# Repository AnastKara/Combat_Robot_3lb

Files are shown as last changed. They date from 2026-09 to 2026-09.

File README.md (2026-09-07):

<!--
  RONIN — 3 lb Combat Robot README
  Placeholders marked [LIKE THIS] are details only you know; fill them in or
  reply and I'll update them.
-->

<div align="center">

# RONIN v1

### 3 lb (1.36 kg) Beetleweight Combat Robot — Horizontal Spinner








</div>

---

##  Quick Navigation

[Overview](#overview) · [Key Features](#key-features) · [Specifications](#technical-specifications) ([Chassis](#chassis) · [Drive](#drive-system) · [Power](#power-system) · [Electronics](#electronics)) · [Weapon](#weapon-system) · [Design & Engineering](#design--engineering) · [Assembly](#assembly-guide) · [Testing](#testing--calibration) · [Maintenance](#maintenance) · [BOM](#bill-of-materials-bom) · [Battle Record](#battle-record) · [Competition Notes](#competition-notes) · [Roadmap](#roadmap) · [Build Files](#build-files) · [Safety](#safety--rules-compliance) · [Credits](#credits) · [License](#license)

---

##  Overview

<div align="center">

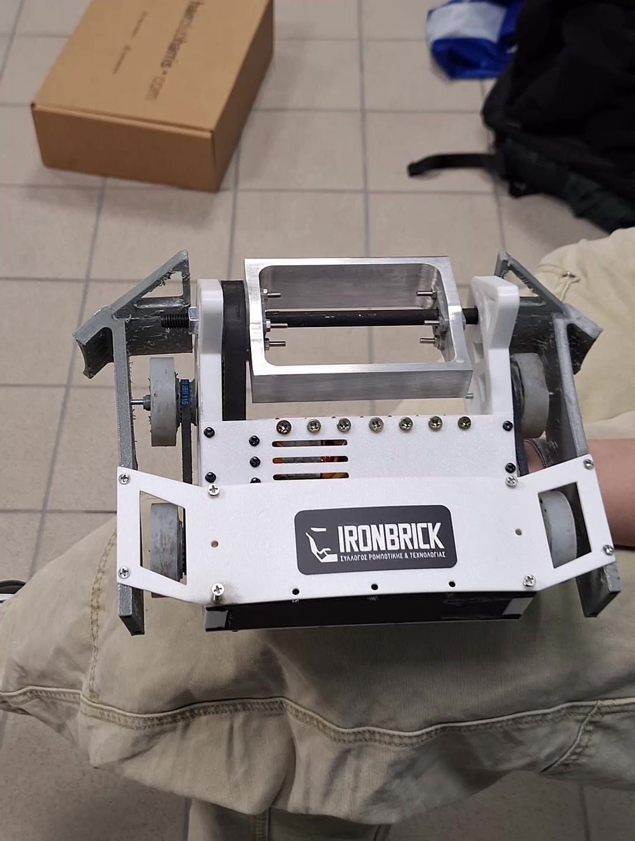
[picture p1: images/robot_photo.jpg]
RONIN v1 — 3 lb horizontal spinner robot
 &nbsp;
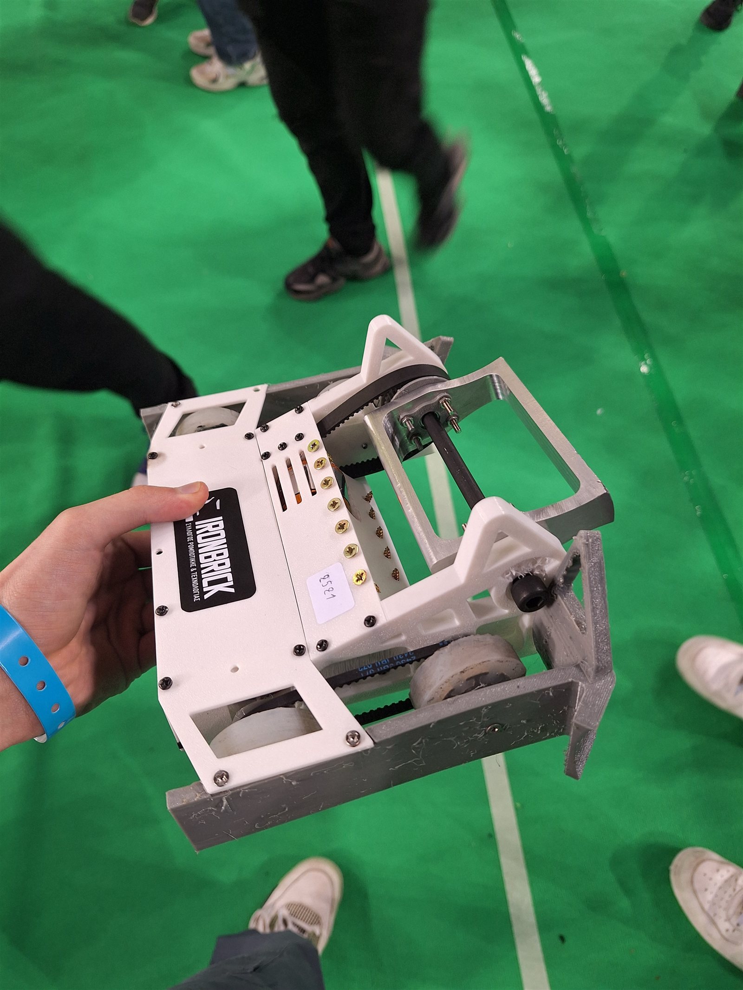
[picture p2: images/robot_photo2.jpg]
RONIN v1 — 3 lb horizontal spinner robot, second view


</div>

> _A compact, belt-driven 3 lb combat robot engineered for durability, ease of
> maintenance, and consistent performance in high-impact matches. RONIN pairs a
> high-energy horizontal spinner with a reinforced front wedge: robust drive
> power, efficient energy distribution, and a pointed front end built for
> pushing, deflecting, and controlling opponents._

Built for the **3 lb (1.36 kg) beetleweight class**, RONIN v1 is designed to be
**serviceable between matches** — a modular two-piece frame with clean wiring
and a lightweight multi-material build (printed PETG / TPU 95A frame with a
7075-T6 aluminum spinner bar) that keeps repair times short and combat
performance consistent. This document covers **RONIN v1**, the first
competition iteration; planned improvements are tracked in the
upgrade roadmap below.

 **Debut result: 2nd place at [MRC 2026](https://minoanrobotsports.gr/)** —
two knockout wins en route to the podium in the 3 lb knockout bracket.

---

##  Key Features

- **Horizontal spinner weapon** — 7075-T6 bar, brushless motor + 80 A ESC
- **Reinforced front wedge** — aggressive pushing, deflection, and positional control
- **Belt-driven dual-wheel drivetrain** — smooth, high-traction torque delivery
- **Modular 2-piece chassis** — fast repairs between matches
- **Shock-resistant electronics mounting** — foam-damped ESCs and secure routing
- **Clean internal wiring** — reliable and quick to troubleshoot
- **Competition-ready layout** — compatible with most 3 lb rule sets

---

##  Technical Specifications

###  Chassis
| Item | Specification |
| --- | --- |
| Material | PETG + TPU 95A (3D printed) |
| Manufacturing| Bambu Lab A1 Mini (FDM) |
| Architecture | 2-piece modular frame |
| Fasteners | M3 / M4 stainless steel |
| Dimensions | 220 × 160 × 91 mm (8.7 × 6.3 × 3.6 in) |
| Weight | **1150 g (2.54 lb)** _(3.0 lb / 1.36 kg max)_ |

###  Drive System
| Item | Specification |
| --- | --- |
| Drive type  | Belt-driven dual-wheel |
| Motor | 2× DartBox V2 Drive gearmotors (VIPER model) |
| Drive ESC | **WEKA 20A** Dual Brushed Motor Controller |
| Mainboard | **Just 'Cuz Motherboard V4** (Just 'Cuz Robotics) |
| Receiver | **FS2A** — AFHDS-2A protocol |
| Wheels | 43 mm (1.7 in) rubber / foam ([Silicon_Wheels](https://github.com/AnastKara/Silicon_Wheels)) |
| Belts | **S3M timing belts** (74 teeth · 4 mm)  |
| Top speed | **~3.5 m/s (12.6 km/h · 7.8 mph)** theoretical · ~2.6 m/s (9.4 km/h) realistic |

###  Power System
| Item | Specification |
| --- | --- |
| Battery | Tattu 3S LiPo · 11.1 V · 450 mAh · 75C |
| Connectors | XT30 |
| Power distribution| DartPCB (Just 'Cuz) |
| Safety | External power switch + removable link |

###  Weapon System
| Item | Specification |
| --- | --- |
| Type | Horizontal spinner (bar) |
| Weapon bar  | **7075-T6 aluminum** |
| Motor | D3536 brushless · **1450 kV** (current)|
| ESC | **80 A** brushless (current) |
| Upgrade | D3536 · 1200 kV + 40 A ESC (planned) |

###  Electronics
| Item | Specification |
| --- | --- |
| Mainboard | **Just 'Cuz Motherboard V4** (Just 'Cuz Robotics) |
| Drive ESC | **WEKA 20A** Dual Brushed Motor Controller |
| Weapon ESC | **80 A** brushless |
| Receiver | **FS2A** — AFHDS-2A protocol |
| Voltage regulation | 5 V BEC for receiver |
| Telemetry | LED status indicator |
| Transmitter | **FlySky FS-i6** — AFHDS-2A |

---

##  Design & Engineering

### Design Philosophy
RONIN is a **horizontal spinner with a control-game edge**. The 7075-T6 bar
delivers high-energy impacts that batter wedges, wheel mounts, and armor,
while the reinforced front wedge lets RONIN push and control opponents when the
weapon is spooled down. That philosophy drives three decisions:

- **Energy + control** — a high-energy weapon bar backed by a strong,
  belt-driven drivetrain that can out-push and out-position most opponents
- **Serviceability** — everything that commonly breaks (belts, wheels, weapon
  bar, drive ESC) is reachable within minutes between fights
- **Efficient weight budget** — the weapon, chassis, and drive get the weight;
  the electronics bay stays tight and clean

### Drivetrain
Two **DartBox V2 Drive gearmotors (VIPER model, 22 mm)** turn both wheels through
**S3M timing belts**, powered by the **WEKA 20A Dual Brushed Motor
Controller** and managed by the **Just 'Cuz Motherboard V4** mainboard. The
DartBox V2 motors are lightweight and ultra-powerful for their size, giving
RONIN a strong power-to-weight ratio. Belt drive reduces shock loading on
the motors and drivetrain during impacts — a key reliability win over direct
chain-drive setups — while the WEKA dual ESC delivers smooth, high-traction
torque for pushing matches.

>  **Top-speed estimate:** Based on the DartBox V2 Drive output (1550 RPM @ 3S)
> and 43 mm wheels, RONIN reaches ~3.5 m/s (12.6 km/h · 7.8 mph) theoretical
> no-load top speed. Accounting for battery sag, friction, and belt losses, a
> realistic figure is ~2.6 m/s (9.4 km/h · 5.9 mph).

| Drivetrain | Electronics |
| --- | --- |
| 2× DartBox V2 Drive (VIPER) + S3M belts | WEKA 20A dual ESC · JCMB V4 · FS2A |

### Weapon
RONIN's primary weapon is a **horizontal spinner bar** machined from
**7075-T6 aluminum**, spinning around a horizontal axis and powered by a
**D3536 brushless motor (1450 kV)** with an **80 A ESC**. The bar delivers
high-energy impacts that batter wedges, wheel mounts, and unprotected chassis.

A reinforced **front wedge** — a low-sweep, angled blade — tucks under
opponents for pushing and positional control when the weapon is down. Wedge
geometry is optimized for **steel arena floors**, and is re-torqued at every
event to keep engagement angle consistent.

| Weapon config | Bar | Motor | ESC |
| --- | --- | --- | --- |
| **Current** | 7075-T6  | D3536 · 1450 kV | 80 A |
| **Planned** | 7075-T6  | D3536 · 1200 kV | 40 A |

>  **Upgrade path:** The planned **D3536 · 1200 kV / 40 A** combination
> lightens the weapon sub-assembly and improves efficiency — trading a little
> top-end weapon speed for a smaller, simpler drive package.

### Chassis & Manufacturing
RONIN's modular frame is **3D printed on a Bambu Lab A1 Mini** in **PETG** for
structural rigidity, with **TPU 95A** parts where flexibility and shock
absorption matter. This multi-material approach keeps the robot lightweight,
reduces part count, and makes it fast to reprint spare parts between events.

---

##  Assembly Guide

### 1. Chassis Preparation
1. Install the front wedge using **M4 bolts**.
2. Mount side panels and check alignment.
3. Add the top plate **last** for easy internal access.

### 2. Drivetrain Installation
1. Mount the drive motors securely; apply **thread-locker**.
2. Align pulleys and tension the S3M belts.
3. Install wheels and verify free rotation.

### 3. Electronics Setup
1. Mount ESCs with **foam tape** for shock absorption.
2. Route motor wires cleanly along chassis walls.
3. Keep the receiver away from high-current lines.
4. Connect: **battery → PD board → ESCs → motors**.

### 4. Final Checks
- [ ] Verify belt tension
- [ ] Confirm correct motor direction
- [ ] Test radio failsafe
- [ ] Inspect all fasteners

---

##  Testing & Calibration

1. **No-load spin-up** — confirm smooth motor ramp with wheels off the ground.
2. **Steering response** — check left/right trim center and full-lock turns.
3. **Wedge engagement** — test on a flat surface; wedge should lift, not bounce.
4. **Thermal soak** — 1–2 minute drive test to confirm ESC and motor
   temperatures stay within limits.

---

##  Maintenance

- **Inspect belts** after every match — replace at the first sign of fraying
- **Re-tighten all screws**, especially the wedge bolts
- **Check motor bearings** for debris and re-grease as needed
- **Replace wheels** when worn to maintain consistent traction
- **Battery care** — keep Tattu 3S LiPos balanced and store them safely (450 mAh nominal)

---

##  Bill of Materials (BOM)

> 📎 CAD files (STEP) for every machined and printed part are in [Build Files](#build-files).

| Component | Specification | Source / Link |
| --- | --- | --- |
| Drive motor | 2× DartBox V2 Drive · VIPER 22 mm | [🔗 DartBox Drive](https://justcuzrobotics.com/products/dartbox-squared-drive) |
| Weapon motor | D3536 brushless · 1450 kV (current) | [🛒 AliExpress](https://www.aliexpress.com/item/1005005039009992.html) |
| Weapon ESC | 80 A brushless (current) | [🛒 AliExpress](https://www.aliexpress.com/item/1005007737723912.html) |
| Drive ESC | WEKA 20A Dual Brushed Motor Controller | [🔗 WEKA 20A](https://justcuzrobotics.com/products/weka-dual-20-esc-for-brushed-drive) |
| Mainboard | Just 'Cuz Motherboard V4 | [🔗 Motherboard V4](https://justcuzrobotics.com/products/motherboard) |
| Power dist. | DartPCB (Just 'Cuz) | [🔗 DartPCB](https://justcuzrobotics.com/products/dartpcb) |
| Receiver | FS2A (AFHDS-2A protocol) | [🛒 AliExpress](https://www.aliexpress.com/item/1005006913201646.html) |
| Battery | Tattu 3S LiPo · 450 mAh · 75C | [🛒 AliExpress](https://www.aliexpress.com/item/1005011861263060.html) |
| Wheels | 43 mm rubber / foam | [🔗 Silicon_Wheels](https://github.com/AnastKara/Silicon_Wheels) |
| Belts | S3M timing belt · 74 teeth · 4 mm | [🔗 S3M 74T Belt](https://justcuzrobotics.com/products/s3m-timing-belt-74t-4mm-wide-used-in-ssp-kits) |
| Weapon pulley  | S3M pulley · 3M-222 · 10 mm width | [🛒 AliExpress](https://www.aliexpress.com/item/1005005935127676.html) |
| Weapon bar | 7075-T6 aluminum (horizontal spinner) | [🔗 CNC (JLC)](https://jlccnc.com/cnc-machining-quote) |
| Weapon shaft | M8 × 160 mm (1 pc) | [🛒 AliExpress](https://www.aliexpress.com/item/1005009038148842.html) |
| Weapon nut | M8 nut (for weapon shaft) | [🛒 AliExpress](https://www.aliexpress.com/item/1005011858105441.html) |
| Chassis | PETG + TPU 95A (Bambu Lab A1 Mini print) | [🔗 Print settings](https://your-link.example/print-file) |
| Connectors | XT30 | [🛒 AliExpress](https://www.aliexpress.com/item/1005005547982922.html) |
| Transmitter | FlySky FS-i6 (AFHDS-2A) | [🛒 AliExpress](https://www.aliexpress.com/item/1005005910087379.html) |
| Fasteners | M3 screw kit · 304 SS · brass thread inserts (M3 × 10 mm) | [🛒 M3 Kit](https://www.aliexpress.com/item/1005007299422418.html) · [🛒 M3 304 SS](https://www.aliexpress.com/item/1005004861140396.html) · [🛒 Brass Inserts](https://www.aliexpress.com/item/1005006472962973.html) |

>  **Sources:** Live links from (AliExpress) and (Just Cuz Robotics).

---

##  Battle Record

| Date | Event | Opponent  | Result | Notes |
| --- | --- | --- | --- | --- |
| 2026-04-05 | [MRC](https://minoanrobotsports.gr/) (Minoan Robot Sports) | Instudies | Win | KO |
| 2026-04-05 | [MRC](https://minoanrobotsports.gr/) (Minoan Robot Sports) | 404 NOT FOUND | Win | KO |
| 2026-04-05 | [MRC](https://minoanrobotsports.gr/) (Minoan Robot Sports) | BigHero 1 | Loss | Battery exploded |

> **Record: 2–1** — two wins (by KO) and one loss at the same MRC event.

###  Tournament Results

| Event | Date | Placement |
|---|---|---|
| [MRC](https://minoanrobotsports.gr/) (Minoan Robot Sports) — 3 lb knockout bracket | 2026-04-05 |  **2nd Place** |

> RONIN fought through the MRC knockout bracket to a **2nd-place finish** — dropping only the semifinal-style bout against BigHero 1 (battery failure) after two KO wins earlier in the day.

---

##  Competition Notes

- Designed for the **3 lb (1.36 kg) beetleweight** class
- Complies with standard safety rules: **removable link** and **LiPo protection**
- Wedge geometry optimized for **steel arena floors**
- Drive tuned for **high-traction pushing matches**

---

##  Upgrade Roadmap — v1 → v2

Completed in **v1** (this build):

- [x] Horizontal spinner weapon — 7075-T6 bar + D3536 (1450 kV) + 80 A ESC
- [x] Belt-driven dual-wheel drivetrain
- [x] Brushed drive + WEKA 20A dual ESC (JCMB V4 / FS2A)

Planned for **v2**:

- [ ] **Weapon upgrade** — D3536 · 1200 kV + 40 A ESC (lighter, more efficient)
- [ ] **Hardened AR500 steel wedge** — more bite and durability
- [ ] **Gyro-assisted driving** — stability under self-righting hits
- [ ] **Quick-swap battery bay** — faster pit stops

---

##  Build Files

All CAD is provided as **STEP** files (universal — open in Fusion 360, SolidWorks, Onshape, FreeCAD…), plus the complete robot as a native **Fusion 360 archive (`.f3z`)**.

###  Full Assembly — `Ronin_V1/Robot/`

| File | Description | Size |
|---|---|---|
| [`ronin_V1.f3z`](Ronin_V1/Robot/ronin_V1.f3z) | Complete robot — native Fusion 360 archive (all sketches, bodies & joints) | ~20 MB |
| [`ronin_V1.step`](Ronin_V1/Robot/ronin_V1.step) | Complete robot — universal STEP assembly | ~15 MB |

###  Machined Parts — `Ronin_V1/Parts/Machined_Parts/` (7075-T6 aluminum)

| Part | File |
|---|---|
| Horizontal spinner bar | [`Horizontal_Spinner.step`](Ronin_V1/Parts/Machined_Parts/Horizontal_Spinner.step) |
| Fork | [`Fork.step`](Ronin_V1/Parts/Machined_Parts/Fork.step) |

###  PETG Parts — `Ronin_V1/Parts/PETG_Parts/` (structural frame · Bambu Lab A1 Mini)

| Part | File |
|---|---|
| Base plate | [`Base_Plate.step`](Ronin_V1/Parts/PETG_Parts/Base_Plate.step) |
| Front plate | [`Front_Plate.step`](Ronin_V1/Parts/PETG_Parts/Front_Plate.step) |
| Back plate | [`Back_Plate.step`](Ronin_V1/Parts/PETG_Parts/Back_Plate.step) |
| Big top plate | [`Big_Top.step`](Ronin_V1/Parts/PETG_Parts/Big_Top.step) |
| Small top plate | [`Small_Top.step`](Ronin_V1/Parts/PETG_Parts/Small_Top.step) |
| Left inside wing | [`Left_Inside_Wing.step`](Ronin_V1/Parts/PETG_Parts/Left_Inside_Wing.step) |
| Right inside wing | [`Right_Inside_Wing.step`](Ronin_V1/Parts/PETG_Parts/Right_Inside_Wing.step) |
| Motor mount (variant 1) | [`Motor_Mount_1.step`](Ronin_V1/Parts/PETG_Parts/Motor_Mount_1.step) |
| Motor mount (variant 2) | [`Motor_Mount_2.step`](Ronin_V1/Parts/PETG_Parts/Motor_Mount_2.step) |
| Shaft spacer | [`Shaft_Spacer.step`](Ronin_V1/Parts/PETG_Parts/Shaft_Spacer.step) |

###  TPU Parts — `Ronin_V1/Parts/TPU_Parts/` (flexible / shock-absorbing · Bambu Lab A1 Mini)

| Part | File |
|---|---|
| Big weapon pulley | [`Big_Weapon_Pulley.step`](Ronin_V1/Parts/TPU_Parts/Big_Weapon_Pulley.step) |
| Small weapon pulley | [`Small_Weapon_Pulley.step`](Ronin_V1/Parts/TPU_Parts/Small_Weapon_Pulley.step) |
| Left outer wing | [`Left_Outer_Wing.step`](Ronin_V1/Parts/TPU_Parts/Left_Outer_Wing.step) |
| Right outer wing | [`Right_Outer_Wing.step`](Ronin_V1/Parts/TPU_Parts/Right_Outer_Wing.step) |

###  Wheels — `Ronin_V1/Parts/Wheels/` (cast silicone tires · [Silicon_Wheels](https://github.com/AnastKara/Silicon_Wheels) project)

| Part | File |
|---|---|
| Front wheel | [`Front_Wheel.step`](Ronin_V1/Parts/Wheels/Front_Wheel.step) |
| Rear wheel | [`Rear_Wheel.step`](Ronin_V1/Parts/Wheels/Rear_Wheel.step) |

> Wheel hub and casting files (including the `Combat_Robot_Silicon_Mold.stl`) live
> in the companion [Silicon_Wheels](https://github.com/AnastKara/Silicon_Wheels)
> repo, along with print settings and the full casting procedure.

---

##  Safety & Rules Compliance

- **Removable link** — power can be broken instantly from outside the arena
- **Hard-cased / secured LiPo** — battery strapped or pocketed securely
- **E-stop** — external power switch for immediate power-down
- Always verify against the **current SPARC / NHRL / event ruleset** before
  competing.

---

##  Credits

RONIN was designed, built, and driven by **Anastasis Karaivazoglou** as part
of the **IRONBRICK | Fibran** team.

Special thanks to our sponsors **[Fibran](https://fibran.com/)** and
**[JLC](https://jlccnc.com/)** for their support of the build.

##  License

**All rights reserved.** © [2026] Anastasis Karaivazoglou / IRONBRICK | Fibran.

This project is provided for reference and personal use only. No part of the
design, documentation, or media may be reproduced, distributed, or used in
commercial or competitive projects without prior written permission.
Sponsors: **[Fibran](https://fibran.com/)** and **[JLC](https://jlccnc.com/)**.

---

_README maintained with the RONIN build. Last updated: September 2026._

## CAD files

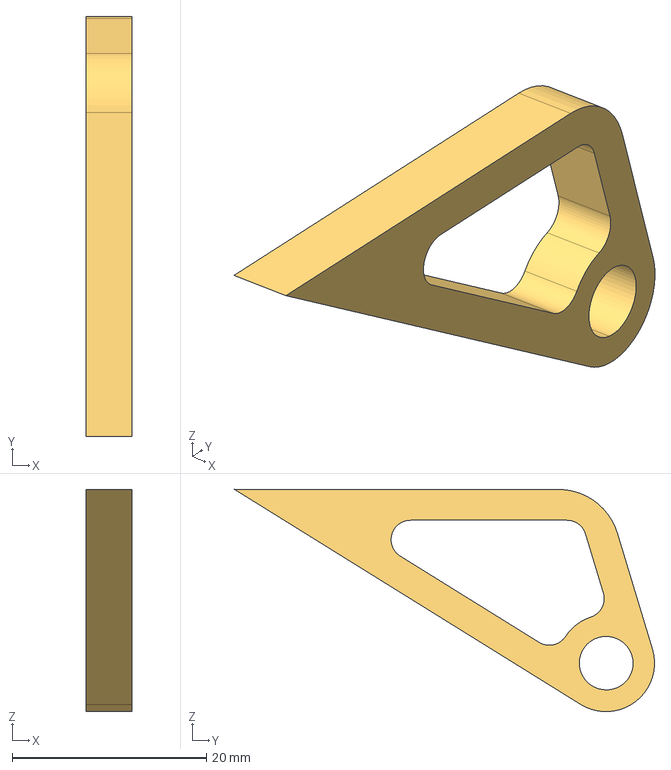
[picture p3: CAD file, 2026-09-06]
Ronin_V1/Parts/Machined_Parts/Fork.step
4.75 x 43.3 x 22.9 mm

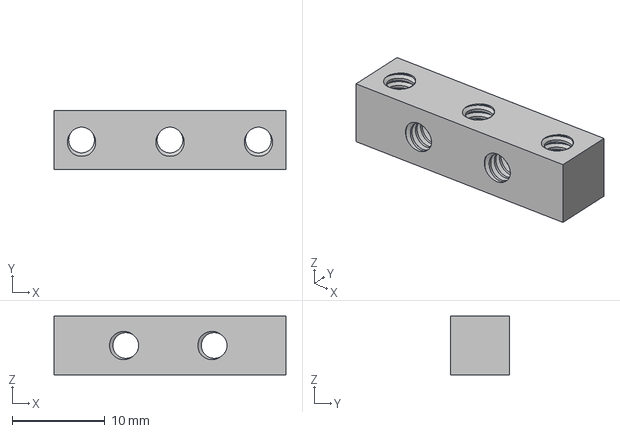
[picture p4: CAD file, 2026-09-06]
Ronin_V1/Parts/PETG_Parts/Motor_Mount_2.step
25.0 x 6.35 x 6.35 mm

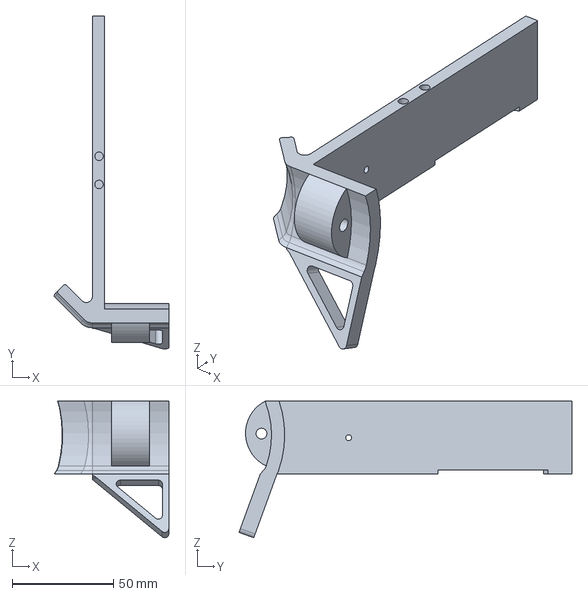
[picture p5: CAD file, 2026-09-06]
Ronin_V1/Parts/TPU_Parts/Left_Outer_Wing.step
56.6 x 164.4 x 67.4 mm

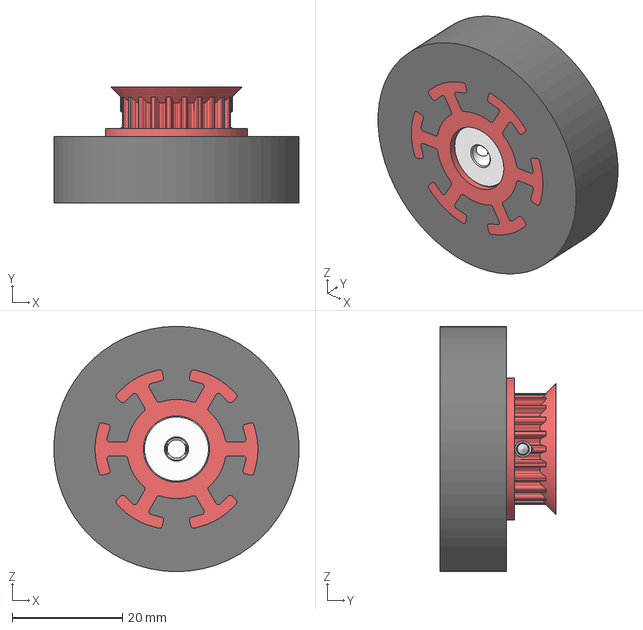
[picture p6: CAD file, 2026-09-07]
Ronin_V1/Parts/Wheels/Rear_Wheel.step
44.4 x 21.0 x 44.4 mm
22t_s3m Wheel
91390A110_Alloy Steel Cup-Point Set Screw x 2

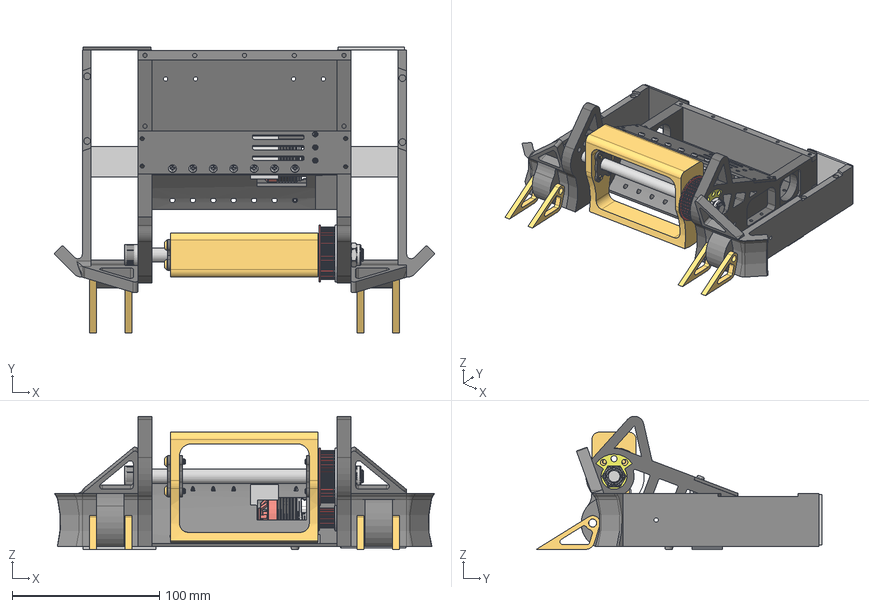
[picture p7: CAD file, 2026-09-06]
Ronin_V1/Robot/ronin_V1.step
257.7 x 193.6 x 90.4 mm
5905K496_Needle-Roller Bearing
91239A148_Button Head Hex Drive Screw x 4
91294A197_Black-Oxide Alloy Steel Hex Drive Flat Head Screw x 4
2315-Mount
23x10-Stator-Plate x 75
694HZZ_SOLID_1-1
694HZZ_SOLID_2-1
694HZZ_SOLID_3-1
SMR84ZZ_SOLID_1
SMR84ZZ_SOLID_2
SMR84ZZ_SOLID_3
23mm-Endbell
2315-Shaft
2315-Magnet x 14
2315-Fluxring
Spacer-4mm x 2
C-Clip-4mm_98541A112
Component120(Mirror) x 2
RR-403-Mk1.0 x 2
Drive Bushings_6391K331.STEP x 2
113-PBK-Mk2.STEP x 2
99461A942_Phillips Rounded Head Thread-Forming Screws x 2
Component120(Mirror)(Mirror) x 2
Component133(Mirror) (2)
Component1(Mirror) (2)
91251A477_Black-Oxide Alloy Steel Socket Head Screw
94945A135_High-Strength Steel Thin Nylon-Insert Locknut
Component139(Mirror)
15T_pulley_dual (1)
99461A941_Phillips Rounded Head Thread-Forming Screws

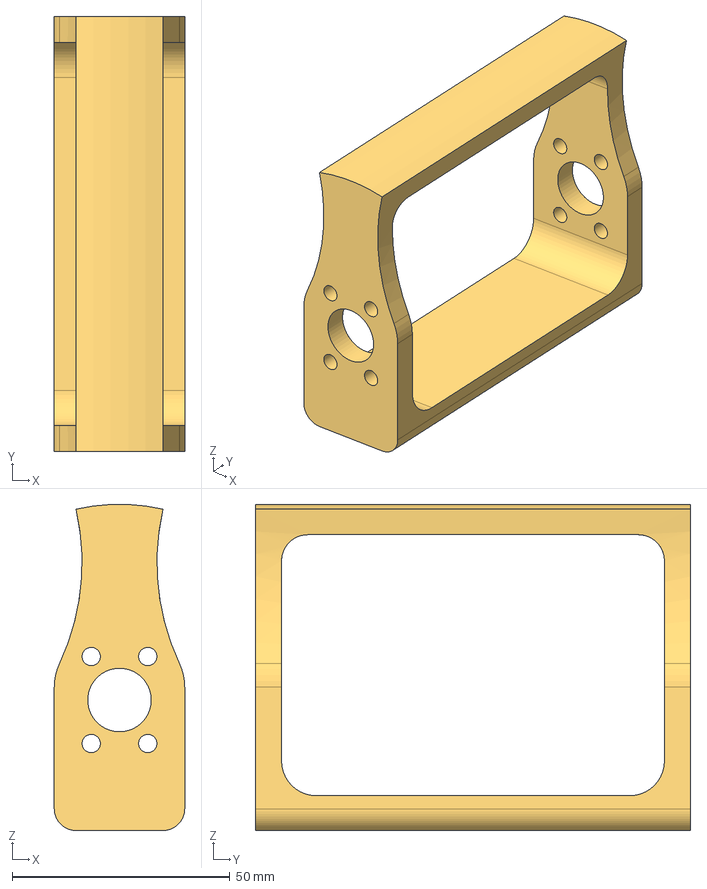
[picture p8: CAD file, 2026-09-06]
Ronin_V1/Parts/Machined_Parts/Horizontal_Spinner.step
30.0 x 100.0 x 75.0 mm

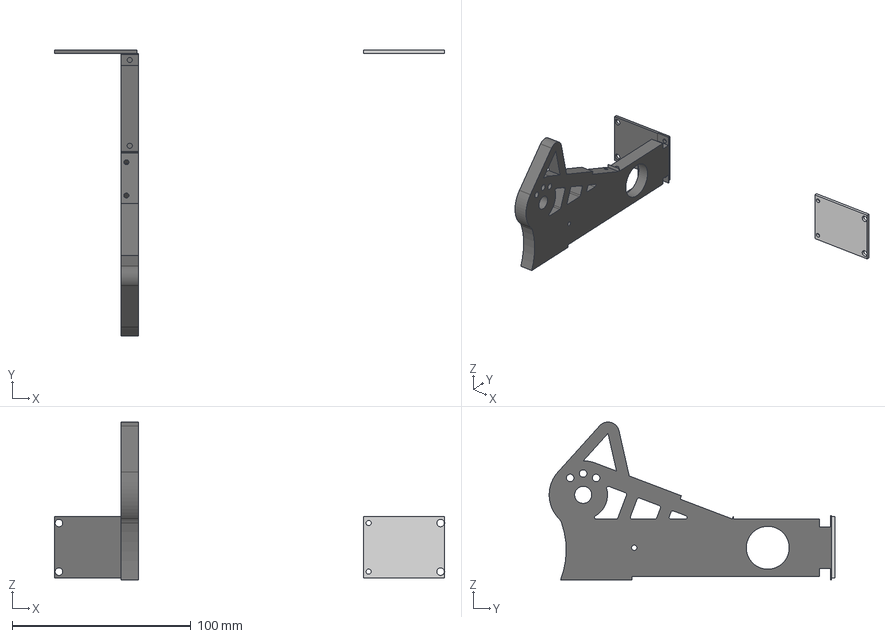
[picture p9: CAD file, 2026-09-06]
Ronin_V1/Parts/PETG_Parts/Right_Inside_Wing.step
218.3 x 159.9 x 88.4 mm

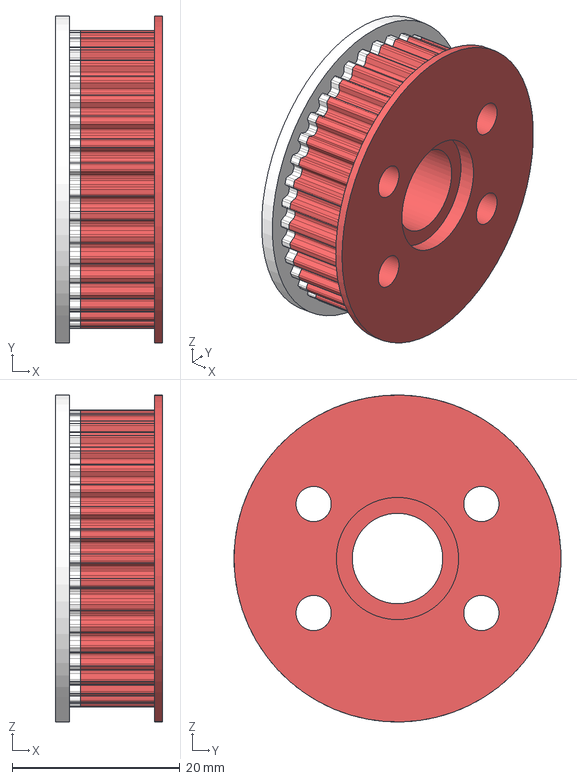
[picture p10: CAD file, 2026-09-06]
Ronin_V1/Parts/TPU_Parts/Big_Weapon_Pulley.step
12.8 x 39.0 x 39.0 mm

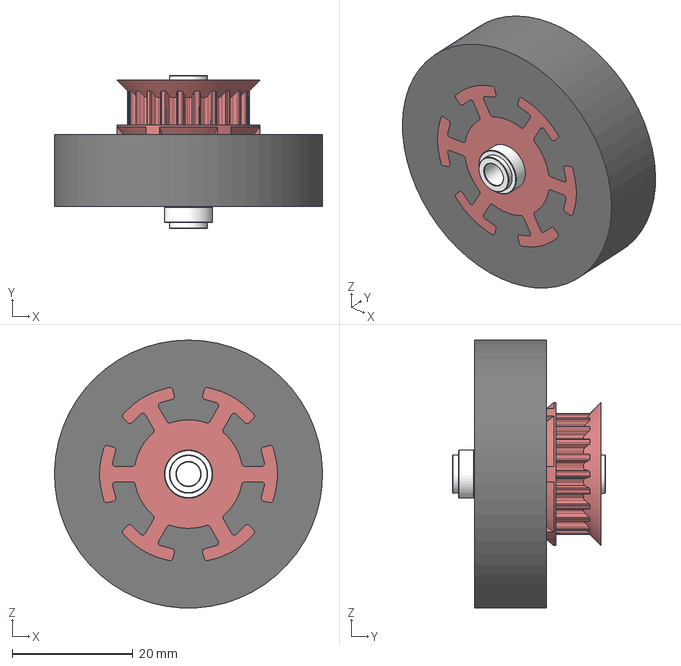
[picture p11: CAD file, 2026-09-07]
Ronin_V1/Parts/Wheels/Front_Wheel.step
44.4 x 25.4 x 44.4 mm
Custom 1in Aluminum Bushing
22t_s3m Wheel

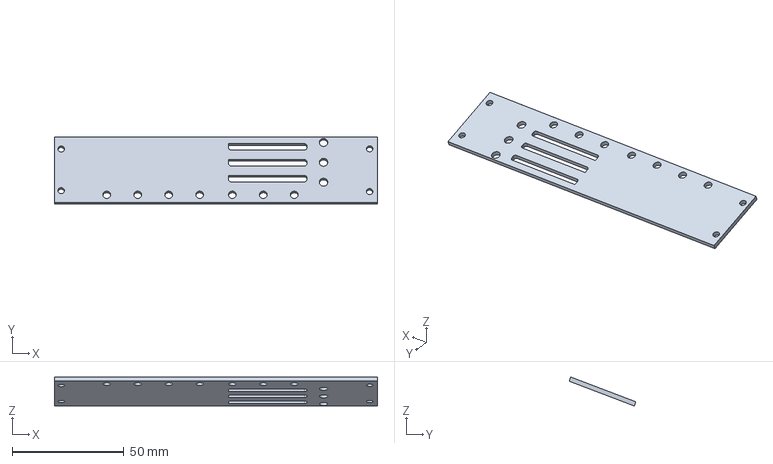
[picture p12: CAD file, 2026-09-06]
Ronin_V1/Parts/PETG_Parts/Small_Top.step
144.5 x 29.9 x 13.0 mm

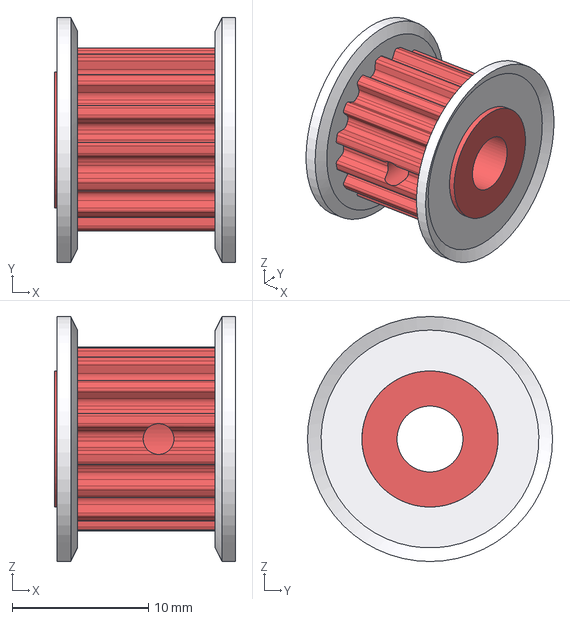
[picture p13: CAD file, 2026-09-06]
Ronin_V1/Parts/TPU_Parts/Small_Weapon_Pulley.step
13.3 x 18.0 x 18.0 mm

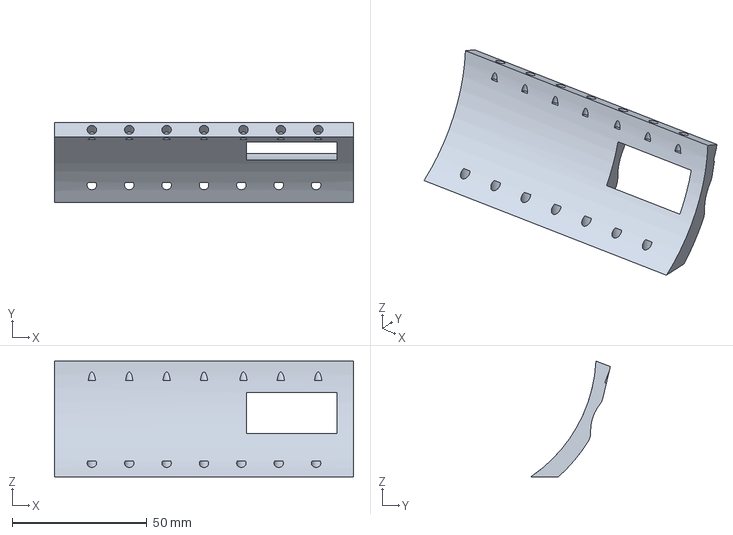
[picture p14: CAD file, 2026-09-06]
Ronin_V1/Parts/PETG_Parts/Front_Plate.step
110.8 x 29.6 x 43.0 mm

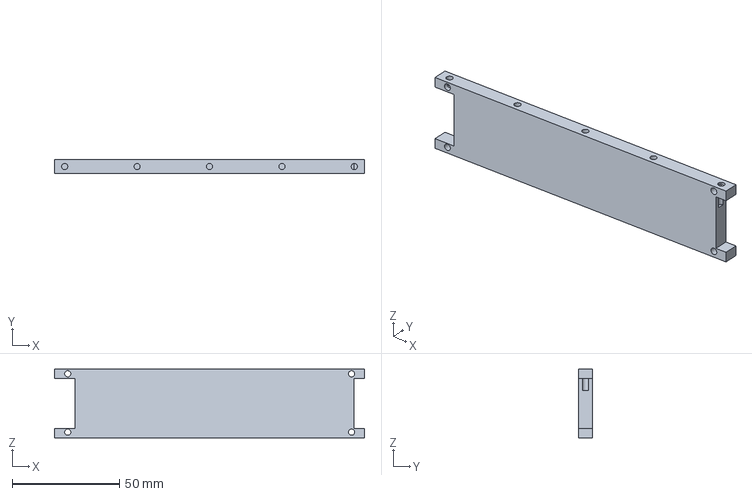
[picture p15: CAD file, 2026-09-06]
Ronin_V1/Parts/PETG_Parts/Back_Plate.step
144.5 x 6.35 x 32.0 mm

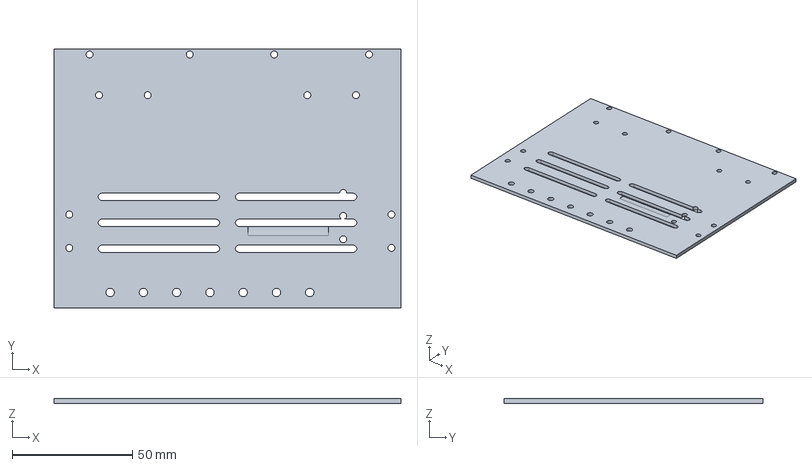
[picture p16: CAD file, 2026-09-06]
Ronin_V1/Parts/PETG_Parts/Base_Plate.step
144.5 x 107.8 x 2.00 mm

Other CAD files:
Ronin_V1/Parts/TPU_Parts/Right_Outer_Wing.step
Ronin_V1/Parts/PETG_Parts/Big_Top.step
Ronin_V1/Parts/PETG_Parts/Motor_Mount_1.step
Ronin_V1/Parts/PETG_Parts/Shaft_Spacer.step
Ronin_V1/Parts/PETG_Parts/Left_Inside_Wing.step
Ronin_V1/Robot/ronin_V1.f3z

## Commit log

2026-09-06 Update RONIN README with full build specs, BOM, and sourcing links
2026-09-06 update 11
    [Back_Plate.step, Base_Plate.step, Big_Top.step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]
2026-09-06 Add full CAD library: Fusion archive, STEP assembly, machined/PETG/TPU part files; document in Build Files
    [Motor_Mount_1.step, Motor_Mount_2.step, Right_Outer_Wing.step]
2026-09-07 update 14
    [Front_Wheel.step, Rear_Wheel.step]
